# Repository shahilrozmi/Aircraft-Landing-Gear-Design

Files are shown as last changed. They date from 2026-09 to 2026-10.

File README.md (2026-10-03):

# Aircraft Landing Gear Design

Preliminary design and structural analysis of an **oleo-pneumatic main landing gear** for a generic 4–6 seat light aircraft. The project combines aircraft load-case definition, nonlinear landing-dynamics simulation, structural sizing, CAD/STEP geometry generation, and progressively refined FEA-oriented structural development using Python-based engineering tools.

## Project Overview

The design focuses on one single-wheel main landing gear leg for a generic low-wing tricycle aircraft.

### Baseline aircraft and landing-gear definition

- Aircraft mass: **1700 kg**
- Wheelbase: **2.35 m**
- Main-gear track: **3.20 m**
- Detailed main-gear wheel lateral offset: **120 mm**
- Static loaded tire radius: **175 mm**
- Physical oleo stroke: **230 mm**
- Static oleo sag: **50 mm**
- Structural ultimate factor: **1.5**

The project is developed progressively from aircraft-level loads and landing energy to component sizing, physical upper-attachment architecture, CAD geometry, FEA load-path validation, local mesh refinement, and geometry redesign.

## Engineering Workflow

### Phase 1 — Aircraft Loads and Landing Dynamics

The authoritative Phase 1 implementation is contained in:

- `phase1_loads/phase1_loads.py`
- `phase1_loads/phase1_dynamics.py`

The landing model uses a **2-DOF tire/oleo representation** with gas-spring and hydraulic-damping behavior.

Selected results:

| Quantity | Result |
|---|---:|
| Nominal peak oleo compression | **206.338 mm** |
| Nominal peak tire deflection | **44.961 mm** |
| Nominal peak ground reaction | **23.800 kN** |
| Nominal peak strut force | **23.038 kN** |
| Zero-lift demanded oleo stroke | **240.779 mm** |
| Zero-lift peak ground reaction | **28.284 kN** |
| Zero-lift peak strut force | **27.781 kN** |

`phase1_model_development/` preserves the development history and robustness studies. Those files are retained for traceability but are **not** the authoritative frozen Phase 1 model.

### Phase 2 — Structural Design and Oleo Architecture

Released preliminary oleo geometry includes:

- Outer barrel: **64 mm ID / 74 mm OD**
- Lower piston: **58 mm OD / 50 mm ID**
- Physical stroke: **230 mm**
- Equivalent orifice schedule: **10.301 → 9.742 mm**
- Fixed metering bore: **14 mm**

Phase 2 includes piston, barrel, bushing/gland, boss, axle, trunnion, brace, overlap/packaging, and traceability work. The repository retains the analytical scripts and associated CSV/TXT engineering records used to develop the architecture.

### Phase 2E3 — Upper Attachment, Physical Brace, and Horn/Clevis Development

The upper attachment evolved beyond the earlier B13C four-body baseline. The validated **B13F-3C** parent is now the retained source geometry for the later physical horn/clevis work.

Current B13F-3C parent highlights:

- 7075-T6 upper-head outer boss: **Ø106 mm × 78 mm**
- Continuous 300M shaft: **Ø38 mm × 175 mm**
- Head side passage: **Ø50 mm**
- Central passage: **Ø44 mm** over the retained center region
- Minimum shaft/head radial gap in the central relief: **3 mm**
- C63000 / AMS 4640 bronze bushings
- Separate 300M thrust collars
- **6 physical bodies** in the validated STEP parent
- Current-parent validation: **54 PASS / 0 FAIL**

The B14 work then physicalized the brace load path and added the source-connected horn/clevis geometry.

Selected B14 milestones:

- B14A source-connected combined brace reaction: **Mx = -16.856 kN·m**
- B14B preliminary physical-brace ultimate force: **67.424 kN**
- B14B-9 physical head/horn/clevis CAD: **62 PASS / 0 FAIL** geometry checks
- B14B-10 global physical-brace FEA load path: **closed** for global reaction/load-path validation and large-deflection sensitivity
- B14B-11: horn/head root transition and local-stress refinement

## Current Root-Transition / FEA Status

The current detailed work is the **B14B-11 root transition**.

### R6 development reference

A local R6 root-mesh sequence reached a design-stage result of **407.52 MPa** at 2.0 mm local sizing with stable global response. This was used as an intermediate reference while the radius trade continued.

### R8 local submodel

A later quadratic local-submodel study showed that the R8 peak was substantially more severe than the earlier coarse full-model screens suggested.

Retained R8 local result:

- 1.50 mm: **442.62 MPa**
- 1.00 mm: **697.48 MPa**
- 0.75 mm: **732.45 MPa**
- 1.00 → 0.75 mm peak change: **+5.014%**
- 0.75 mm fillet-average VM: **91.817 MPa**
- Maximum deformation: **0.73252 mm**

The 0.75 mm solution is treated as **near-converged / mesh-stabilized**, not as strictly mathematically converged. Under the generic project 7075 static screen, the **732.45 MPa** local peak is unacceptable and requires a geometry response.

### F2 reinforced-root redesign

The first B14B-11F redesign retained the basic root architecture but enlarged the section:

- **F2_BALANCED:** **95 × 115 mm** root section, **R12** blend
- Added mass versus the R8 head: approximately **0.615 kg**

A 1.0 mm local submodel gave:

- **24,801 nodes / 14,487 elements**
- Maximum deformation: **0.73252 mm**
- Fillet-average VM: **77.072 MPa** (**16.1% lower** than the retained R8 average)
- Fillet-scoped peak VM: **1995.7 MPa**

The extreme peak occurs at the termination of the new blend. Therefore **F2 is rejected as-is**, while the **95 × 115 mm reinforced-section concept is retained**.

## Current Next Step

**B14B-11F / F2B root redesign**:

- retain the **95 × 115 mm** reinforced root concept
- replace the abrupt constant-radius blend termination with a smoother/tangent transition
- rerun the **1.0 mm quadratic local screen**
- only refine to **0.75 mm** after the local peak becomes physically credible and the transition geometry is accepted
- update the full six-body parent only after the local redesign passes the screening gate

## Repository Structure

```text
Aircraft-Landing-Gear-Design/
├── README.md
├── CURRENT_STATE.md
├── UPLOAD_MANIFEST.md
├── FILE_INVENTORY.csv
├── requirements.txt
│
├── phase1_loads/
│   ├── phase1_loads.py
│   ├── phase1_dynamics.py
│   └── frozen CSV outputs
│
├── phase1_model_development/
│   ├── README.md
│   └── historical Phase 1 model revisions
│
└── phase2_structures/
    ├── preliminary component sizing / architecture
    ├── E2 release and traceability records
    ├── B13 / B13F upper-head and trunnion development
    ├── B14 physical-brace / horn-clevis development
    ├── B14B-10 FEA handoff and closeout records
    ├── B14B-11 radius trade / local-submodel / convergence work
    ├── B14B-11F redesign candidates
    └── current_design/
        └── retained B13-era interface sizing records
```

## Running the Python Analyses

Create a virtual environment and install the retained dependencies:

```bash
python -m venv .venv
```

Windows:

```bash
.venv\Scripts\activate
pip install -r requirements.txt
```

Principal Phase 1 analyses:

```bash
python phase1_loads/phase1_loads.py
python phase1_loads/phase1_dynamics.py
```

Phase 2 contains multiple design-stage scripts rather than one monolithic program. See `CURRENT_STATE.md` and `UPLOAD_MANIFEST.md` for the current analysis chain and authoritative revisions.

## Remaining Work

Major later-stage items include:

- F2B root-transition redesign and local FEA screen
- final horn/head root geometry selection and full-parent confirmation solve
- local stress convergence of the accepted geometry
- production fit and running-clearance definition
- lubrication, wear, and fretting assessment
- fatigue and fracture analysis
- final shaft-retention hardware
- detailed tolerances and surface finishes
- corrosion protection
- complete airframe attachment definition
- certification / regulatory load mapping
- finalized landing-gear assembly and detailed component geometry in CATIA V5
- optional retraction-mechanism development

## Project Notes

`CURRENT_STATE.md` is the recommended starting point for the latest engineering status.

`UPLOAD_MANIFEST.md` identifies the retained/current analysis chain and explains the curation rules used for GitHub.

This repository represents an **educational preliminary engineering design project**, not a certified aircraft component design.

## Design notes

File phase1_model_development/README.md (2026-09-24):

# Phase 1 Model Development Archive

These scripts are retained as **historical engineering evidence**, not as the current source of truth.

For current/frozen Phase 1 results, use:

- `../phase1_loads/phase1_loads.py`
- `../phase1_loads/phase1_dynamics.py`
- `../phase1_loads/phase1_load_envelope.csv`
- `../phase1_loads/phase1_dynamic_robustness.csv`

The archived scripts all execute successfully in the current audit environment, but they represent the model-development chain that led to the frozen consolidated model.

## What each archived script shows

- `landing_dynamic_v1.py` — V0.3 predecessor: 1-DOF energy-equivalent oleo model, hand-analysis targets, gas sizing, and smooth hydraulic metering. Useful for showing how the 205 mm target stroke and 10.301 -> 9.742 mm metering schedule were established. Superseded by the 2-DOF model for final landing loads.
- `landing_dynamic_v04_2dof.py` — V0.4 2-DOF sprung/unsprung tire-oleo model. Reproduces the accepted nominal result (206.338 mm stroke, 23.800 kN ground reaction, 23.038 kN strut force), extension-stop release, energy balance, and 20/30/40 kg unsprung-mass sensitivity.
- `landing_dynamic_v05_robustness.py` — V0.5 robustness study. Contains the unsprung-mass, sink-speed, **tire-stiffness**, and retained-lift sweeps plus selected combined robustness corners. The tire-stiffness sweep and combined corner studies are useful development evidence and are not all duplicated in the consolidated `phase1_dynamics.py`.
- `landing_dynamic_v05b_virtual_stroke.py` — V0.5b zero-lift virtual-stroke diagnostic. Reproduces the accepted 3.048 m/s zero-lift demand (240.779 mm stroke, 28.284 kN ground reaction, 27.781 kN strut force) and also evaluates the 1.10 Vd zero-lift case (248.258 mm demanded stroke).

## Interpretation rule

If an archived development result differs in framing or screening status from the frozen Phase 1 sources, the files in `phase1_loads/` govern. Do not use this archive to retune the frozen model unless the project is deliberately reopened.

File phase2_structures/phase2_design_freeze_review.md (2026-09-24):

# Landing_Gear_Design_Project — Phase 2 Preliminary Design Baseline V1

**Review outcome:** PRELIMINARY BASELINE READY — OPEN DETAIL/PACKAGING ITEMS REMAIN

This report is generated from the Phase 1 / Phase 2 CSV calculation chain. Calculated stresses, reactions, and margins are not transcribed from chat.

## Status summary

| Status | Count |
|---|---:|
| FROZEN | 11 |
| LOCK_PRELIMINARY | 22 |
| KEEP_PARAMETRIC | 8 |
| DEFER_DETAIL_FEA | 2 |

## Baseline

| Subsystem | Parameter | Value | Unit | Status | Source |
|---|---|---:|---|---|---|
| Project / frozen input | Aircraft mass | 1700.0 | kg | FROZEN | Phase 0 / Phase 1 / Phase 2B |
| Project / frozen input | Screening weight used in Phase 1 | 16.68 | kN | FROZEN | Phase 0 / Phase 1 / Phase 2B |
| Project / frozen input | Wheelbase | 2.35 | m | FROZEN | Phase 0 / Phase 1 / Phase 2B |
| Project / frozen input | Main-gear track | 3.2 | m | FROZEN | Phase 0 / Phase 1 / Phase 2B |
| Project / frozen input | Wheel/strut lateral offset e | 120.0 | mm | FROZEN | Phase 0 / Phase 1 / Phase 2B |
| Project / frozen input | Static loaded tire radius | 175.0 | mm | FROZEN | Phase 0 / Phase 1 / Phase 2B |
| Project / frozen input | Physical oleo stroke | 230.0 | mm | FROZEN | Phase 0 / Phase 1 / Phase 2B |
| Project / frozen input | Static oleo sag | 50.0 | mm | FROZEN | Phase 0 / Phase 1 / Phase 2B |
| Project / frozen input | Full-extension U-to-A length | 525.0 | mm | FROZEN | Phase 0 / Phase 1 / Phase 2B |
| Project / frozen input | Static U-to-A length | 475.0 | mm | FROZEN | Phase 0 / Phase 1 / Phase 2B |
| Project / frozen input | Ultimate factor | 1.5 | - | FROZEN | Phase 0 / Phase 1 / Phase 2B |
| Lower piston | Structural OD | 58.0 | mm | LOCK_PRELIMINARY | phase2_piston_sizing.csv |
| Lower piston | Wall thickness | 4.0 | mm | LOCK_PRELIMINARY | phase2_piston_sizing.csv |
| Outer barrel | Bore / ID | 64.0 | mm | LOCK_PRELIMINARY | phase2_barrel_sizing.csv |
| Outer barrel | Smooth wall thickness | 5.0 | mm | LOCK_PRELIMINARY | phase2_barrel_sizing.csv |
| Outer barrel | Smooth OD | 74.0 | mm | LOCK_PRELIMINARY | phase2_barrel_sizing.csv |
| Guide system | Lower bushing static station h_L | 250.0 | mm above axle | LOCK_PRELIMINARY | phase2_packaging_overlap.csv |
| Guide system | Bushing spacing | 150.0 | mm | LOCK_PRELIMINARY | phase2_packaging_overlap.csv |
| Guide system | Upper bushing static station h_U | 400.0 | mm above axle | LOCK_PRELIMINARY | phase2_packaging_overlap.csv |
| Guide system | Bushing axial length | 30.0 | mm | LOCK_PRELIMINARY | phase2_bushing_material_gland_requirements.csv |
| Guide system | Bushing material | C63000 / AMS 4640 Ni-Al bronze |  | LOCK_PRELIMINARY | phase2_bushing_material_gland_requirements.csv |
| Guide system | Bushing radial wall | 3.0 | mm | LOCK_PRELIMINARY | phase2_bushing_material_gland_requirements.csv |
| Guide / packaging | Top guide-surface overrun | 20.0 | mm | KEEP_PARAMETRIC | phase2_packaging_overlap.csv |
| Guide / packaging | Required piston guide-surface length | 485.0 | mm | KEEP_PARAMETRIC | phase2_packaging_overlap.csv |
| Gland | Architecture | Integral shoulder + bronze guide/seal carrier + threaded gland nut |  | LOCK_PRELIMINARY | phase2_gland_retainer_sizing.csv |
| Gland | Thread envelope | M70 x 2 equivalent 60-deg envelope |  | KEEP_PARAMETRIC | phase2_gland_retainer_sizing.csv |
| Gland | Thread engagement | 12.0 | mm | KEEP_PARAMETRIC | phase2_gland_retainer_sizing.csv |
| Lower barrel boss | Local boss OD | 84.0 | mm | LOCK_PRELIMINARY | phase2_gland_retainer_sizing.csv |
| Lower barrel boss | Boss-to-smooth-barrel transition land | 15.0 | mm | KEEP_PARAMETRIC | phase2_lower_barrel_boss_sizing.csv |
| Lower barrel boss | Actual fillet radius / local Kt | OPEN |  | DEFER_DETAIL_FEA | phase2_lower_barrel_boss_sizing.csv |
| Axle / spindle | Smooth root OD | 50.0 | mm | LOCK_PRELIMINARY | phase2_axle_sizing.csv |
| Axle / spindle | Smooth root wall | 8.0 | mm | LOCK_PRELIMINARY | phase2_axle_sizing.csv |
| Axle / spindle | Axle-to-piston local transition | OPEN |  | DEFER_DETAIL_FEA | phase2_axle_sizing.csv |
| Upper attachment | Trunnion architecture | Two bearings on +x axis + independent Mx brace path |  | LOCK_PRELIMINARY | phase2_upper_trunnion_sizing.csv |
| Upper attachment | Trunnion journal diameter | 32.0 | mm | LOCK_PRELIMINARY | phase2_upper_trunnion_sizing.csv |
| Upper attachment | Trunnion bearing width | 25.0 | mm | LOCK_PRELIMINARY | phase2_upper_trunnion_sizing.csv |
| Upper attachment | Trunnion support span | 120.0 | mm | KEEP_PARAMETRIC | phase2_upper_trunnion_sizing.csv |
| Upper brace | Tube OD | 25.0 | mm | LOCK_PRELIMINARY | phase2_upper_brace_sizing.csv |
| Upper brace | Tube wall | 3.0 | mm | LOCK_PRELIMINARY | phase2_upper_brace_sizing.csv |
| Upper brace | Pin diameter | 18.0 | mm | LOCK_PRELIMINARY | phase2_upper_brace_sizing.csv |
| Upper brace | Pin-bushing projected width | 20.0 | mm | LOCK_PRELIMINARY | phase2_upper_brace_sizing.csv |
| Upper brace | Effective perpendicular moment arm | 250.0 | mm | KEEP_PARAMETRIC | phase2_upper_brace_sizing.csv |
| Upper brace | Pin-to-pin free length | 350.0 | mm | KEEP_PARAMETRIC | phase2_upper_brace_sizing.csv |

## Compatibility / structural review

| Check | Result | Detail | Severity |
|---|---|---|---|
| Piston OD matches D5 bearing interface | PASS | piston OD = 58.0 mm | REQUIRED |
| Bushing OD matches barrel bore | PASS | bushing OD = 64.0 mm, barrel ID = 64.0 mm | REQUIRED |
| Bushing radial stack is self-consistent | PASS | (barrel ID - piston OD)/2 = 3.0 mm, D5 bushing wall = 3.0 mm | REQUIRED |
| Full lower-bushing engagement at physical stroke | PASS | reserve = +55.0 mm | REQUIRED |
| Full lower-bushing engagement in V0.5b diagnostic | PASS | reserve = +44.2 mm | DIAGNOSTIC |
| Local gland boss is thicker than smooth barrel | PASS | boss OD = 84.0 mm, smooth barrel OD = 74.0 mm | REQUIRED |
| Gland boss retains positive thread-root wall | PASS | boss root wall = 7.00 mm | REQUIRED |
| Gland nut retains positive root wall over through-bore | PASS | gland root wall = 4.27 mm | REQUIRED |
| Piston preliminary structural screen | PASS | ultimate VM = 1023.2 MPa, MS = +0.820 | REQUIRED |
| Barrel preliminary structural/pressure screen | PASS | ultimate VM = 595.2 MPa, MS = +2.128 | REQUIRED |
| Lower boss transition at review Kt | PASS | Kt = 2.0, ultimate VM = 230.1 MPa, MS = +7.091 | REQUIRED |
| Axle root preliminary screen | PASS | ultimate VM = 481.2 MPa, MS = +2.870 | REQUIRED |
| Upper trunnion preliminary screen | PASS | ultimate VM = 460.0 MPa, bearing p = 101.9 MPa | REQUIRED |
| Upper brace tube preliminary screen | PASS | MS ultimate = +8.530, MS buckling = +3.871 | REQUIRED |
| Upper brace pin/bushing preliminary screen | PASS | pin shear MS = +12.505, bearing MS = +2.676 | REQUIRED |
| Upper Mx load path exists | PASS | brace effective arm = 250 mm; calculated ultimate brace force = 40.51 kN | REQUIRED |
| Axle-to-piston local root geometry resolved | OPEN | smooth piston ID = 50.0 mm and axle OD = 50.0 mm; this is not a through-fit requirement, but the forged/welded/local axle-to-piston transition has not yet been defined | OPEN_DETAIL |
| Physical upper-barrel/cavity package above U resolved | OPEN | current packaging model requires 190.0 mm piston-top intrusion above equivalent datum U at physical stroke | OPEN_PACKAGING |
| Actual trunnion/brace airframe fitting geometry resolved | OPEN | journal spacing and brace arm/free length remain preliminary until airframe fitting CAD is established | OPEN_PACKAGING |

## Open items

| Priority | Item | Resolution gate |
|---|---|---|
| HIGH | Axle-to-piston lower-end architecture | Detailed lower-strut CAD + local stress/FEA |
| HIGH | Upper barrel / piston cavity above equivalent datum U | Full strut packaging CAD |
| HIGH | Physical trunnion / brace airframe fitting coordinates | Airframe-interface CAD / structural arrangement |
| MEDIUM | Gland production thread / lock / seal definition | Detailed gland design |
| MEDIUM | Actual fillet radii and stress concentrations | Detailed CAD + FEA/fatigue |
| MEDIUM | Wheel bearing seats / brake flange / wheel-retention spindle detail | Wheel/brake interface design |
| MEDIUM | Brace clevis/lug/pin bending details | Detailed upper-joint design |
| LATER | Fatigue / fracture / fretting / corrosion / surface treatment | Later structural substantiation phase |
| LATER | Retraction mechanism | Optional later extension |

## Baseline rule

Items marked **LOCK_PRELIMINARY** are now the Phase 2 baseline and should be used by downstream analyses unless a deliberate design-change decision reopens them. **KEEP_PARAMETRIC** items remain active packaging variables. **DEFER_DETAIL_FEA** items are intentionally unresolved until the appropriate detailed-design stage.

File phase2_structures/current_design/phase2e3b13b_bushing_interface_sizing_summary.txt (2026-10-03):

======================================================================================================================
 DOCUMENTATION BACKFILL — current_design\phase2e3b13b_bushing_interface_sizing.py
======================================================================================================================

Python executable: C:\Users\Shahi\AppData\Local\Python\pythoncore-3.14-64\python.exe
Working directory: C:\Users\Shahi\OneDrive\Documents\Python\Landing_Gear_Project_UPLOAD_v2\phase2_structures\current_design
Return code: 0

STDOUT
----------------------------------------------------------------------------------------------------------------------
============================================================================================================
 PHASE 2E3-B13B — SHAFT / HEAD BUSHING INTERFACE PRELIMINARY SIZING V0.1
============================================================================================================

--- INPUT / ARCHITECTURE BASIS ---
300M shaft nominal diameter:                38.000 mm
7075 head OD, working CAD input:           106.000 mm
AMS 4640 static bearing screen:            413.685 MPa
B2 recovered reference reaction:           112.640 kN
B12 conservative per-bushing envelope:     166.160 kN
Load note: B12 reaction is intentionally used as a conservative per-bushing screen;
           B13C contact FEA will resolve the actual bushing load distribution.

--- STATIC-BEARING MINIMUM LENGTHS ---
Length required at B2 reference reaction:    7.165 mm
Length required at B12 envelope:            10.570 mm
Interpretation: static projected bearing capacity alone does NOT control a 25–30 mm bushing length.

--- PRACTICAL SHORTLIST FILTERS (NON-CERTIFICATION / PACKAGING ONLY) ---
Minimum candidate length retained:          25.000 mm
Minimum bronze radial wall retained:         5.000 mm
Minimum head radial ligament retained:      25.000 mm

--- PRACTICAL SHORTLIST ---
    L    OD    wall  head lig      gap      p_ID    MS_brg      p_OD
----------------------------------------------------------------------------
   25    48    5.00     29.00    56.00     174.9     1.365     138.5
   25    50    6.00     28.00    56.00     174.9     1.365     132.9
   25    52    7.00     27.00    56.00     174.9     1.365     127.8
   25    54    8.00     26.00    56.00     174.9     1.365     123.1
   25    56    9.00     25.00    56.00     174.9     1.365     118.7
   30    48    5.00     29.00    46.00     145.8     1.838     115.4
   30    50    6.00     28.00    46.00     145.8     1.838     110.8
   30    52    7.00     27.00    46.00     145.8     1.838     106.5
   30    54    8.00     26.00    46.00     145.8     1.838     102.6
   30    56    9.00     25.00    46.00     145.8     1.838      98.9
   35    48    5.00     29.00    36.00     124.9     2.311      98.9
   35    50    6.00     28.00    36.00     124.9     2.311      94.9
   35    52    7.00     27.00    36.00     124.9     2.311      91.3
   35    54    8.00     26.00    36.00     124.9     2.311      87.9
   35    56    9.00     25.00    36.00     124.9     2.311      84.8

--- WORKING CANDIDATE FOR B13B/B13C DEVELOPMENT ---
Nominal shaft / bushing ID:                 38.000 mm
Bushing OD:                                 50.000 mm
Bushing length, each side:                  30.000 mm
Bronze radial wall:                          6.000 mm
Remaining head radial ligament:             28.000 mm
Central unbushed gap:                       46.000 mm
Shaft-side projected p @ B12 envelope:     145.754 MPa
AMS 4640 static bearing MS:                 +1.838
Housing-side projected p, descriptive:     110.773 MPa

SELECTION REASON
- Ø50 x 30 mm gives a 6 mm bronze wall and 28 mm current-CAD head radial ligament.
- Its 30 mm length is far above the static-capacity mathematical minimum.
- It preserves a practical, round geometry for the next interference-fit/contact study.
- This is a WORKING candidate, not a final certified bushing dimension.

--- OPEN ITEMS BEFORE GEOMETRY FREEZE ---
1. Bronze-to-7075 interference/retention fit: DEFERRED to B13B V0.2.
2. Shaft-to-bushing running clearance:       TBD from fit/lubrication/wear basis.
3. 7075 bearing/net-section/shear-out:        requires local head mechanics / FEA.
4. Fretting, wear, lubrication, fatigue:      OPEN.
5. Actual bushing reaction split:             resolve in B13C nonlinear contact FEA.

OUTPUT FILES
Full candidate sweep: C:\Users\Shahi\OneDrive\Documents\Python\Landing_Gear_Project_UPLOAD_v2\phase2_structures\current_design\phase2e3b13b_bushing_trade.csv
Summary:              C:\Users\Shahi\OneDrive\Documents\Python\Landing_Gear_Project_UPLOAD_v2\phase2_structures\current_design\phase2e3b13b_summary.txt
============================================================================================================

STDERR
----------------------------------------------------------------------------------------------------------------------

======================================================================================================================

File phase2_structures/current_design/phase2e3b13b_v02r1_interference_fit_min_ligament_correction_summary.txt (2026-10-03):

======================================================================================================================
 DOCUMENTATION BACKFILL — current_design\phase2e3b13b_v02r1_interference_fit_min_ligament_correction.py
======================================================================================================================

Python executable: C:\Users\Shahi\AppData\Local\Python\pythoncore-3.14-64\python.exe
Working directory: C:\Users\Shahi\OneDrive\Documents\Python\Landing_Gear_Project_UPLOAD_v2\phase2_structures\current_design
Return code: 0

STDOUT
----------------------------------------------------------------------------------------------------------------------
==========================================================================================================
 PHASE 2E3-B13B V0.2R1 — INTERFERENCE-FIT MINIMUM-LIGAMENT CORRECTION
==========================================================================================================

--- CORRECTED GEOMETRY INTERPRETATION ---
Head lateral width:                     106.000 mm
Head minimum vertical height:            78.000 mm
Bushing seat diameter:                   50.000 mm
Minimum vertical ligament:               14.000 mm
Side ligament:                           28.000 mm
V0.2's 28 mm value was the SIDE ligament, not the minimum ligament.

--- CORRECTED FIT SENSITIVITY ---
  delta_d     p_fit     VM7075     MS7075    VMbronze    MSbronze
----------------------------------------------------------------------
    0.005      1.53       4.63    107.738        7.25      56.119
    0.010      3.06       9.25     53.369       14.50      27.559
    0.015      4.59      13.88     35.246       21.74      18.040
    0.020      6.12      18.50     26.184       28.99      13.280
    0.025      7.65      23.13     20.748       36.24      10.424
    0.030      9.18      27.75     17.123       43.49       8.520
    0.040     12.25      37.01     12.592       57.98       6.140
    0.050     15.31      46.26      9.874       72.48       4.712
    0.060     18.37      55.51      8.061       86.98       3.760
    0.080     24.49      74.01      5.796      115.97       2.570
    0.100     30.62      92.52      4.437      144.96       1.856
    0.150     45.92     138.77      2.625      217.44       0.904
    0.200     61.23     185.03      1.718      289.92       0.428

--- LINEAR ELASTIC FIRST SCREEN ---
7075 yield surrogate:                     0.544 mm diametral interference
Bronze proof surrogate:                   0.286 mm diametral interference
First material screen:                    0.286 mm
Interpretation: the corrected minimum-ligament surrogate still leaves tens-of-micrometre
fit sensitivities comfortably elastic. This does NOT define the production fit.

OUTPUT FILES
CSV:     C:\Users\Shahi\OneDrive\Documents\Python\Landing_Gear_Project_UPLOAD_v2\phase2_structures\current_design\phase2e3b13b_v02r1_interference_sweep.csv
Summary: C:\Users\Shahi\OneDrive\Documents\Python\Landing_Gear_Project_UPLOAD_v2\phase2_structures\current_design\phase2e3b13b_v02r1_summary.txt
==========================================================================================================

STDERR
----------------------------------------------------------------------------------------------------------------------

======================================================================================================================

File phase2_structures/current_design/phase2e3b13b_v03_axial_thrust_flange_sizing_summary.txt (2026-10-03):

======================================================================================================================
 DOCUMENTATION BACKFILL — current_design\phase2e3b13b_v03_axial_thrust_flange_sizing.py
======================================================================================================================

Python executable: C:\Users\Shahi\AppData\Local\Python\pythoncore-3.14-64\python.exe
Working directory: C:\Users\Shahi\OneDrive\Documents\Python\Landing_Gear_Project_UPLOAD_v2\phase2_structures\current_design
Return code: 0

STDOUT
----------------------------------------------------------------------------------------------------------------------
================================================================================================================
 PHASE 2E3-B13B V0.3 — FLANGED-BUSHING AXIAL THRUST-PATH PRELIMINARY SIZING
================================================================================================================

--- FROZEN / WORKING INPUTS ---
LC5 limit |Fx|:                           8.87376 kN
LC5 ultimate |Fx|:                       13.31064 kN
Shaft / bushing nominal ID:                38.000 mm
Sleeve OD:                                 50.000 mm
Sleeve length each side:                   30.000 mm
Head face -> bearing inner edge gap:        9.500 mm
AMS 4640 preliminary static screen:       413.685 MPa

--- ARCHITECTURE RULE ---
One flanged bushing may conservatively carry the full axial |Fx| in either direction.
Mx remains on the independent brace path; flange/shaft retention is NOT credited for Mx.

--- CANDIDATE TRADE ---
   Df    tf   seat_w    pBr_ult     MS_Br    pAl_ult   gap_rem    pkg
----------------------------------------------------------------------------------
   52   2.0     1.00      13.45    29.756      83.08      7.50   OPEN
   52   3.0     1.00      13.45    29.756      83.08      6.50   OPEN
   52   4.0     1.00      13.45    29.756      83.08      5.50   OPEN
   52   5.0     1.00      13.45    29.756      83.08      4.50   OPEN
   54   2.0     2.00      11.51    34.931      40.74      7.50   OPEN
   54   3.0     2.00      11.51    34.931      40.74      6.50   OPEN
   54   4.0     2.00      11.51    34.931      40.74      5.50   OPEN
   54   5.0     2.00      11.51    34.931      40.74      4.50   OPEN
   56   2.0     3.00      10.02    40.301      26.65      7.50   OPEN
   56   3.0     3.00      10.02    40.301      26.65      6.50   OPEN
   56   4.0     3.00      10.02    40.301      26.65      5.50   OPEN
   56   5.0     3.00      10.02    40.301      26.65      4.50   OPEN
   58   2.0     4.00       8.83    45.866      19.62      7.50   PASS
   58   3.0     4.00       8.83    45.866      19.62      6.50   PASS
   58   4.0     4.00       8.83    45.866      19.62      5.50   PASS
   58   5.0     4.00       8.83    45.866      19.62      4.50   PASS
   60   2.0     5.00       7.86    51.627      15.41      7.50   PASS
   60   3.0     5.00       7.86    51.627      15.41      6.50   PASS
   60   4.0     5.00       7.86    51.627      15.41      5.50   PASS
   60   5.0     5.00       7.86    51.627      15.41      4.50   PASS
   62   2.0     6.00       7.06    57.583      12.61      7.50   PASS
   62   3.0     6.00       7.06    57.583      12.61      6.50   PASS
   62   4.0     6.00       7.06    57.583      12.61      5.50   PASS
   62   5.0     6.00       7.06    57.583      12.61      4.50   PASS
   64   2.0     7.00       6.39    63.734      10.62      7.50   PASS
   64   3.0     7.00       6.39    63.734      10.62      6.50   PASS
   64   4.0     7.00       6.39    63.734      10.62      5.50   PASS
   64   5.0     7.00       6.39    63.734      10.62      4.50   PASS

--- WORKING FLANGE FOR B13C CAD/FEA ---
Flange OD:                                 60.000 mm
Flange thickness:                           3.000 mm
Positive radial seat on 7075 face:          5.000 mm
Bronze thrust pressure, ultimate:           7.861 MPa
Bronze static-screen margin:              +51.627
7075 head-face avg pressure, ultimate:     15.407 MPa
Gap remaining before bearing inner edge:    6.500 mm

SELECTION REASON
- Static axial thrust pressure is extremely low relative to the preliminary bronze screen.
- Ø60 gives a 5 mm radial positive seat outside the Ø50 sleeve bore.
- 3 mm flange thickness leaves 6.5 mm of the current 9.5 mm external gap.
- Thickness is a PROVISIONAL packaging/FEA starting value; static face pressure does not size it.
- Flange-root bending, local 7075 face stress, washer detail, wear and fatigue remain for FEA/detail design.

--- RESULTING B13C GEOMETRY INTENT ---
Per side bronze bushing: sleeve Ø50 OD x Ø38 nominal ID x 30 mm long
                         integral flange Ø60 OD x 3 mm thick
Two bushings are inserted from opposite sides of the head.
The flange is the positive axial seat; the shaft shoulder/thrust washer acts on the bronze flange.
The center of the head must NOT retain an exposed Ø38 aluminum land that can touch the shaft.

--- IMPORTANT OPEN ITEM FOR CAD ---
Central shaft clearance/relief diameter is NOT frozen in V0.3.
For B13C geometry, either keep the full head passage relieved to the Ø50 bushing OD,
or deliberately size a smaller central relief bore > Ø38 after a clearance/tolerance study.
Do NOT leave the old Ø38 7075 bore exposed between the two bushings.

OUTPUT FILES
Trade CSV: C:\Users\Shahi\OneDrive\Documents\Python\Landing_Gear_Project_UPLOAD_v2\phase2_structures\current_design\phase2e3b13b_v03_thrust_flange_trade.csv
Summary:   C:\Users\Shahi\OneDrive\Documents\Python\Landing_Gear_Project_UPLOAD_v2\phase2_structures\current_design\phase2e3b13b_v03_summary.txt
================================================================================================================

STDERR
----------------------------------------------------------------------------------------------------------------------

======================================================================================================================

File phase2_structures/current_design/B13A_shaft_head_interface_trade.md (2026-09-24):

# Phase 2E3-B13A — Shaft / Head Interface Architecture Trade

## Working architecture

**Selected working concept:** removable Ø38 mm 300M cross-pin running in two replaceable
C63000 / AMS 4640 nickel-aluminum-bronze head bushings.

Load path:

`7075-T6 head -> bronze bushings -> 300M shaft -> external airframe bearings`

The independent brace / lock-link remains the reaction path for `Mx`.

## Why B13 exists

B12/B12C showed that the extreme local head stress was controlled by the termination of the
idealized bonded shaft/head interface. A head-only path offset approximately 0.5 mm from that
termination dropped to roughly 191–238 MPa, while the exact interface edge remained far higher.
The bonded model is therefore retained only as historical sensitivity evidence, not as the final
physical interface.

## Concept trade

| Concept | Benefit | Main drawback | B13 disposition |
|---|---|---|---|
| Direct 300M-to-7075 interference fit | simple, rigid | adds fit stress directly to 7075; poorer serviceability | not preferred |
| Replaceable bronze bushings + removable pin | replaceable wear surface; realistic pin joint | needs fit/contact analysis | **working selection** |
| Split/clamped boss | removable and rigidizable | more parts, preload and package complexity | reserve option |

## Freeze boundary

B13A freezes the *architecture*, not final dimensions.

Working starting dimensions for B13B:
- shaft nominal diameter: 38 mm
- current CAD head OD input: 106 mm
- bushing material: C63000 / AMS 4640 nickel-aluminum bronze
- initial practical candidate explored: 50 mm OD × 30 mm length per side

Still open:
- bronze-to-7075 interference/retention fit
- shaft running clearance
- lubrication/wear/fretting
- final bushing OD and length
- 7075 local bearing/net-section/shear-out
- nonlinear contact FEA

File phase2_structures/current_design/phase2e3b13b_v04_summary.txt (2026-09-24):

================================================================================================================
 PHASE 2E3-B13B V0.4 — CENTRAL SHAFT RELIEF / HEAD-SECTION TRADE
================================================================================================================

--- BASELINE ---
Head cross-section:                    106.0 x 78.0 mm
Original bore:                         Ø38.0 mm
Original upper/lower ligament:         20.0 mm
Original side ligament:                34.0 mm

--- RELIEF TRADE ---
  Drel   clr_r   v_lig   s_lig      dA%     dIy%     dIz%   sig_sens    MSsens
--------------------------------------------------------------------------------------
    40    1.00   19.00   33.00    -1.72    -0.57    -0.31      56.46     7.908
    42    2.00   18.00   32.00    -3.52    -1.23    -0.66      59.60     7.439
    44    3.00   17.00   31.00    -5.42    -2.00    -1.07      63.11     6.971
    46    4.00   16.00   30.00    -7.40    -2.87    -1.54      67.05     6.502
    48    5.00   15.00   29.00    -9.47    -3.87    -2.07      71.52     6.033
    50    6.00   14.00   28.00   -11.63    -5.00    -2.68      76.63     5.564

--- WORKING B13C CENTRAL RELIEF ---
Selected working relief:              Ø50.0 mm THROUGH
Shaft-to-aluminum radial clearance:    6.00 mm
Minimum vertical ligament:             14.00 mm
Side ligament:                         28.00 mm
Net-area change vs Ø38 bore:           -11.63 %
Iy change vs Ø38 bore:                 -5.00 %
Iz change vs Ø38 bore:                 -2.68 %
B11 scaled nominal stress sensitivity: 76.63 MPa
Yield margin on that sensitivity only: +5.564

SELECTION REASON
- Ø50 through-bore matches the bronze sleeve OD and eliminates exposed Ø38 aluminum.
- It avoids an internal bore shoulder at the bushing ends.
- It gives 6 mm radial clearance between the Ø38 shaft and 7075 center passage.
- Relative to the old Ø38 bore, the centered-section area falls about 11.6%,
  Iy about 5.0%, and Iz about 2.7%; these are acceptable to TAKE TO FEA, not final approval.
- The minimum vertical ligament becomes 14 mm, so B13C local head/contact FEA is mandatory.

B13C CAD INTENT
- Machine/model one Ø50 passage through the head.
- Install one 30 mm-long flanged bronze bushing from each side.
- Leave the center 46 mm of the Ø50 passage unoccupied.
- Shaft is Ø38 nominal; it contacts bronze ID surfaces only, never 7075.
- Keep the Ø60 x 3 mm flange working geometry from B13B V0.3.
- Do not add a central keeper hole/keyway through the Ø38 shaft.
- Mx remains on the independent brace path.

OUTPUT FILES
Trade CSV: C:\Users\Shahi\OneDrive\Documents\Python\Landing_Gear_Project\phase2_structures\current_design\phase2e3b13b_v04_central_relief_trade.csv
Summary:   C:\Users\Shahi\OneDrive\Documents\Python\Landing_Gear_Project\phase2_structures\current_design\phase2e3b13b_v04_summary.txt
================================================================================================================

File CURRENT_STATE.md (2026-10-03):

# Landing Gear Design Project — Current Repository State

This repository is a curated engineering snapshot for continued development, reproducibility, and traceability. Large machine-specific Python environments, caches, and superseded artifacts are intentionally excluded.

## Authoritative project state

### Phase 1 — frozen loads and landing dynamics

Use `phase1_loads/phase1_loads.py` and `phase1_loads/phase1_dynamics.py` as the authoritative Phase 1 sources.

Frozen load-envelope highlights:

- LC1 / LC2 / LC3 vertical limit per detailed main: **25.02 kN**; ultimate **37.53 kN**
- LC4 vertical limit per main: **11.0922 kN** with lateral **±8.34 kN**
- LC5 limit: **Fx = -8.87376 kN**, **Fz = 11.0922 kN**
- LC5 ultimate: **Fx = -13.31064 kN**, **Fz = 16.6383 kN**

Landing-dynamics highlights:

- Nominal peak oleo stroke: **206.338 mm**
- Nominal peak tire deflection: **44.961 mm**
- Nominal peak ground reaction: **23.800 kN**
- Nominal peak strut force: **23.038 kN**
- Zero-lift virtual-stroke demand: **240.779 mm**
- Zero-lift peak ground reaction: **28.284 kN**
- Zero-lift peak strut force: **27.781 kN**

`phase1_model_development/` remains a non-authoritative development-history archive.

### Phase 2E2 — released preliminary oleo architecture

`phase2_structures/phase2e2_v1_release_report.txt` remains the authoritative E2 release record.

Release status: **PASS (22/22 checks)** at preliminary architecture / structural-screen level.

Released working geometry / hydraulic architecture:

- barrel: **64 mm ID / 74 mm OD**
- piston: **58 mm OD / 50 mm ID**
- physical stroke: **230 mm**
- smooth clamped-linear equivalent orifice: **10.301 → 9.742 mm over 205 mm**
- fixed metering bore: **14 mm**
- preliminary E3 interface: **498.780 mm above U**

### Phase 2E3 — upper-head / trunnion evolution

B1–B12 remain the retained design history leading to the B13 family.

The previous GitHub snapshot stopped at the **B13C** four-body geometry. That geometry is now historical rather than the active CAD parent.

#### Current retained parent — B13F-3C

The validated parent for the later B14 horn/clevis work is:

`phase2_structures/phase2e3_b13f_3c_d44_r1p5_t3p5_left_collar_partial_relief.step`

Key geometry:

- 7075-T6 upper-head boss: **Ø106 × 78 mm**
- continuous 300M shaft: **Ø38 × 175 mm**
- head side passage: **Ø50 mm**
- central passage: **Ø44 mm** over the retained center region
- minimum shaft/head radial gap: **3 mm**
- right bronze sleeve: **Ø50/Ø38 × 30 mm**
- left bronze flange: **Ø60/Ø38 × 3.5 mm**
- separate left/right 300M thrust collars
- physical bodies: **6**
- validation: **54 PASS / 0 FAIL**

The validation record explicitly supersedes the old B13C model as the current parent for B14B-9.

## B14 physical-brace / horn-clevis development

### B14A — source-connected ANSYS reaction record

`phase2e3b14a_freeze_record.csv` is the load-source handoff for later B14B work.

Combined brace reaction:

- **Mx = -16.856 kN·m**
- force + moment + pressure superposition residual: **0.001260%**

### B14B — physical brace

The physical brace architecture converts the frozen B14A moment reaction into an axial two-force member.

Working values:

- effective Mx arm: **250 mm**
- pin-to-pin length: **350 mm**
- ultimate brace force: **67.424 kN**
- tube working section: **25 mm OD × 3 mm wall**

### B14B-9 — physical horn / clevis CAD

`phase2e3b14b9_head_horn_clevis_v01.step` adds the source-connected horn/clevis to the validated B13F-3C parent.

- equivalent root section entering the horn: **85 × 95 mm**
- pin bore: **Ø18 mm**
- geometry validation: **62 PASS / 0 FAIL**
- gate: `PASS_B14B9_GEOMETRY_FOR_LOCAL_FEA`

### B14B-10 — physical-brace FEA closeout

B14B-10 is **closed for global physical-brace load-path validation and large-deflection sensitivity**.

The large-deflection sensitivity showed only small changes in global response, including approximately:

- brace-force magnitude: **-0.0283%**
- maximum deformation: **+0.1484%**
- maximum von Mises stress: **+0.0144%**

The sharp horn/head root remained the governing local hotspot, so the next work moved to local transition refinement rather than treating the B14B-10 local maximum as final.

## B14B-11 — horn/head root transition refinement

### R6 development reference

The R6 local root-mesh sequence reached:

- 3.0 mm: **411.23 MPa**
- 2.5 mm: **408.46 MPa**
- 2.0 mm: **407.52 MPa**

The 2.5 → 2.0 mm change was **0.230%**, so R6 was considered converged enough for that design stage.

### R8 local submodel

Later targeted refinement showed that the raw full-model root maximum was not a reliable converged local stress. A quadratic local-submodel workflow was therefore created.

Retained R8 convergence sequence:

- 1.50 mm: **442.62 MPa**
- 1.00 mm: **697.48 MPa**
- 0.75 mm: **732.45 MPa**

At 0.75 mm:

- nodes/elements: **19,081 / 11,045**
- fillet-average VM: **91.817 MPa**
- maximum total deformation: **0.73252 mm**
- 1.00 → 0.75 mm peak change: **+5.014%**

Disposition:

- treat **732.45 MPa** as the current conservative R8 local design-screen peak
- describe it as **near-converged / mesh-stabilized**, not strictly converged
- the generic 7075 project static screen is exceeded
- the R8 geometry therefore requires redesign or a later allowable-based justification before any final design freeze

## Current design-response checkpoint — B14B-11F

Two reinforced-root concepts were generated from the R8 response target.

### F2_BALANCED

- root section: **95 × 115 mm**
- nominal blend: **R12 mm**
- added mass vs R8 head: approximately **0.615 kg**

1.0 mm local-screen result:

- mesh: **24,801 nodes / 14,487 elements**
- maximum deformation: **0.73252 mm**
- fillet-average VM: **77.072 MPa**
- fillet peak VM: **1995.7 MPa**
- peak location: approximately **(40.753, 37.334, 994.066) mm**

The average stress decreased by about **16.1%** from the retained R8 result while the local peak rose dramatically. The peak sits at/near the termination of the redesigned blend, identifying a local transition problem rather than a global section-load increase.

### Current disposition

**F2 V1 is rejected as-is.**

The **95 × 115 mm reinforced-root concept is retained** because the section response is promising, but the abrupt constant-radius blend termination must be replaced.

## Immediate next engineering step

**Design F2B**:

1. retain the **95 × 115 mm** root concept
2. replace the abrupt constant-radius blend termination with a smoother/tangent transition
3. preserve the established local-submodel cut/mapping convention
4. rerun the candidate at **1.0 mm quadratic local sizing**
5. inspect peak location, peak/average behavior, displacement consistency, and geometry credibility
6. only proceed to **0.75 mm** refinement after the 1.0 mm screen is physically credible
7. after local acceptance, update the full six-body parent and run the parent confirmation solve

F3 remains a fallback concept; it has not superseded the retained F2 section concept at this checkpoint.

## File-use rule

When multiple files cover the same analysis, prefer the highest/current revision identified in `UPLOAD_MANIFEST.md` and the explicit closeout/final-assessment records. Do not restore superseded development versions merely because they exist in an older local archive.

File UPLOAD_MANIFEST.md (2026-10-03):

# Upload Manifest

This repository is the curated GitHub state of the landing-gear project. The local working archive remains larger and may contain machine-specific environments, temporary solver material, and superseded development artifacts that are intentionally not versioned.

## Authoritative / latest core revisions

### Phase 1

- `phase1_loads/phase1_loads.py`
- `phase1_loads/phase1_dynamics.py`

### Phase 2 architecture / release chain

- `phase2_structures/phase2_traceability_audit_v04.py`
- `phase2_structures/phase2_traceability_v1_freeze_update.py`
- `phase2_structures/phase2e1_lower_end_architecture_v04.py`
- `phase2_structures/phase2e2_oleo_cavity_packaging_v03.py`
- `phase2_structures/phase2e2_metering_upper_head_layout_v04.py`
- `phase2_structures/phase2e2_metering_law_comparison_v03.py`
- `phase2_structures/phase2e2b_upper_head_closure_audit_v03.py`
- `phase2_structures/phase2e2c_fluid_continuity_closure_finalize_v01.py`
- `phase2_structures/phase2e2_v1_release_audit.py`

### Phase 2E3 B1–B13 retained chain

- `phase2_structures/phase2e3a_upper_attachment_source_audit_v01.py`
- `phase2_structures/phase2e3a2_upper_attachment_fbd_transport_v01.py`
- `phase2_structures/phase2e3b1_trunnion_centerline_trade_v01.py`
- `phase2_structures/phase2e3b2_trunnion_coupled_sizing_v01.py`
- `phase2_structures/phase2e3b3_trunnion_shortlist_head_integration_v01.py`
- `phase2_structures/phase2e3b4_cross_trunnion_head_interface_v01.py`
- `phase2_structures/phase2e3b5_local_head_interface_screen_v01.py`
- `phase2_structures/phase2e3b5a_barrel_material_upper_neck_audit_v01.py`
- `phase2_structures/phase2e3b5b_upper_barrel_reinforcement_profile_v01.py`
- `phase2_structures/phase2e3b6_head_span_recoupling_v01.py`
- `phase2_structures/phase2e3b6a_working_candidate_local_refresh_v02.py`
- `phase2_structures/phase2e3b7_transition_kt_budget_trade_v02.py`
- `phase2_structures/phase2e3b7a_expanded_transition_robustness_trade_v01.py`
- `phase2_structures/phase2e3b7b_transition_fea_handoff_v01.py`
- `phase2_structures/phase2e3b8_transition_fea_load_package_v01.py`
- `phase2_structures/phase2e3b9_fea_convergence_closeout_v01.py`
- `phase2_structures/phase2e3b9a_large_deflection_closeout_v01.py`
- `phase2_structures/phase2e3b10_upper_head_trunnion_integration.py`
- `phase2_structures/phase2e3b10a_retention_architecture_closeout.py`
- `phase2_structures/phase2e3b11_upper_head_local_screens.py`
- `phase2_structures/phase2e3b12_generate_integrated_model.py`
- `phase2_structures/current_design/phase2e3b13b_bushing_interface_sizing.py`
- `phase2_structures/current_design/phase2e3b13b_v02r1_interference_fit_min_ligament_correction.py`
- `phase2_structures/current_design/phase2e3b13b_v03_axial_thrust_flange_sizing.py`
- `phase2_structures/current_design/phase2e3b13b_v04_central_relief_trade.py`
- `phase2_structures/current_design/phase2e3b13c_build_geometry_portable_v2.py`

### B13F current-parent validation

- `phase2_structures/phase2e3_b13f3c_current_parent_validation_v01_resend.py`

Current retained parent STEP:

- `phase2_structures/phase2e3_b13f_3c_d44_r1p5_t3p5_left_collar_partial_relief.step`

### B14 physical brace / horn-clevis chain

- `phase2_structures/phase2e3b14a_ansys_reaction_documentation_v01.py`
- `phase2_structures/phase2e3b14b_brace_physicalization_v01.py`
- `phase2_structures/phase2e3b14b4_horn_clevis_detail_trade_v01.py`
- `phase2_structures/phase2e3b14b5_horn_robustness_shortlist_v01.py`
- `phase2_structures/phase2e3b14b6_head_packaging_gate_v01.py`
- `phase2_structures/phase2e3b14b7_saddle_root_reinforcement_trade_v01.py`
- `phase2_structures/phase2e3b14b8_physical_clevis_geometry_v01.py`
- `phase2_structures/phase2e3b14b9_build_physical_horn_clevis_v01.py`
- `phase2_structures/phase2e3b14b10_physical_brace_fea_handoff_v02.py`
- `phase2_structures/phase2e3b14b10_contact_geometry_audit_v01.py`
- `phase2_structures/phase2e3b14b10_contact_smoothing_diagnostic_v01.py`
- `phase2_structures/phase2e3b14b10_post_smoothing_linear_baseline_compare_v01.py`
- `phase2_structures/phase2e3b14b10_large_deflection_sensitivity_v01.py`
- `phase2_structures/phase2e3b14b10_closeout_record_v01.py`

### B14B-11 root-transition / local-FEA chain

- `phase2_structures/phase2e3b14b11_root_transition_trade_v01.py`
- `phase2_structures/phase2e3b14b11b_build_r6_root_fillet_v01.py`
- `phase2_structures/phase2e3b14b11_r6_local_convergence_closeout_v01.py`
- `phase2_structures/phase2e3b14b11c_build_r4_r8_trade_variants_v01.py`
- `phase2_structures/phase2e3b14b11c_corrected_r4_r6_r8_trade_v01.py`
- `phase2_structures/phase2e3b14b11c_r8_ridge_edge_refinement_assessment_v01.py`
- `phase2_structures/phase2e3b14b11d_build_r8_root_submodel_v01.py`
- `phase2_structures/phase2e3b14b11e_build_r8_root_local_solid_v01.py`
- `phase2_structures/phase2e3b14b11e_r8_fillet_convergence_v03_final_assessment.py`
- `phase2_structures/phase2e3b14b11f_r8_design_response_targets_v01.py`
- `phase2_structures/phase2e3b14b11f_root_redesign_trade_v01.py`
- `phase2_structures/phase2e3b14b11f_build_root_redesign_candidates_v01.py`
- `phase2_structures/phase2e3b14b11f_f2_balanced_screen_diagnostic_v01.py`

## Critical current records / CAD artifacts

### Frozen aircraft / oleo basis

- `phase1_loads/phase1_load_envelope.csv`
- `phase1_loads/phase1_dynamic_robustness.csv`
- `phase2_structures/phase2e2_v1_release_report.txt`
- `phase2_structures/phase2_traceability_register_v1.csv`
- `phase2_structures/phase2_open_validation_items_v1.csv`
- `phase2_structures/phase2_traceability_v1_summary.txt`

### Current-parent and B14 load-path records

- `phase2_structures/phase2e3_b13f3c_current_parent_record.csv`
- `phase2_structures/phase2e3_b13f3c_current_parent_summary.txt`
- `phase2_structures/phase2e3_b13f_3c_d44_r1p5_t3p5_left_collar_partial_relief.step`
- `phase2_structures/phase2e3b14a_freeze_record.csv`
- `phase2_structures/phase2e3b14a_summary.txt`
- `phase2_structures/phase2e3b14b9_head_horn_clevis_v01.step`
- `phase2_structures/phase2e3b14b9_summary.txt`
- `phase2_structures/phase2e3b14b10_closeout_summary_v01.txt`

### Current local-root / redesign records

- `phase2_structures/phase2e3b14b11_r6_local_convergence_closeout_v01.txt`
- `phase2_structures/phase2e3b14b11c_corrected_r4_r6_r8_trade_v01.txt`
- `phase2_structures/phase2e3b14b11d_r8_root_submodel_v01.step`
- `phase2_structures/phase2e3b14b11e_r8_root_local_solid_v01.step`
- `phase2_structures/phase2e3b14b11e_r8_fillet_convergence_v03_final_assessment.txt`
- `phase2_structures/phase2e3b14b11f_candidate_summary_v01.txt`
- `phase2_structures/phase2e3b14b11f_f2_balanced_full_sixbody_v01.step`
- `phase2_structures/phase2e3b14b11f_f2_balanced_local_submodel_v01.step`
- `phase2_structures/phase2e3b14b11f_f2_balanced_screen_diagnostic_v01.txt`
- `phase2_structures/phase2e3b14b11f_root_redesign_trade_v01.txt`

## Retained supporting analyses

The repository intentionally keeps unique trade, audit, sizing, FEA-handoff, convergence, and CAD-variant records when they provide engineering traceability, even when they are not the final/current design.

This includes:

- `phase1_model_development/` as a clearly labeled historical Phase 1 archive
- B1–B12 design trade history
- B13/B13F geometry-development variants and reports
- B14 brace, horn/clevis, packaging, and CAD handoff records
- B14B-10 contact/setup diagnostics
- B14B-11 R4/R6/R8 radius-trade and convergence diagnostics
- R8 local-submodel construction and validation records
- F2/F3 redesign-candidate CAD and screening records
- documentation backfill / traceability audit outputs that improve the engineering record

## Current checkpoint

The current design checkpoint is **B14B-11F after the F2_BALANCED 1.0 mm local screen**.

- retained R8 local peak: **732.45 MPa @ 0.75 mm**
- F2 root section: **95 × 115 mm**, nominal **R12** blend
- F2 fillet-average VM: **77.072 MPa**
- F2 local peak: **1995.7 MPa** at the new blend termination
- disposition: **F2 V1 rejected as-is; reinforced-section concept retained**

Next engineering action: **F2B transition redesign** with a smoother/tangent blend termination, followed by a repeat 1.0 mm quadratic local screen.

## Intentionally excluded from GitHub

### Machine / IDE material

- `phase2_structures/.venv_cad/` — local Windows Python/CadQuery environment; recreate from `requirements.txt`
- any other `.venv*`, `venv/`, cache, or compiled-bytecode directories
- `*.code-workspace` — local editor workspace state

### Known superseded / unwanted artifacts

The earlier exclusions remain in force, including superseded Phase 2 traceability/E1/E2 revisions, superseded B6A/B7 revisions, obsolete B13B V0.2 interference-fit outputs, and the older B13C builders superseded by `portable_v2`.

Additionally:

- `phase2_structures/phase2e3b7a_working_profile.csv` — empty artifact from a trade with no passing working profile; do not restore it

## Recommended reading order for continuation

1. `CURRENT_STATE.md`
2. `phase1_loads/phase1_load_envelope.csv`
3. `phase1_loads/phase1_dynamic_robustness.csv`
4. `phase2_structures/phase2e2_v1_release_report.txt`
5. `phase2_structures/phase2e3_b13f3c_current_parent_summary.txt`
6. `phase2_structures/phase2e3b14a_summary.txt`
7. `phase2_structures/phase2e3b14b9_summary.txt`
8. `phase2_structures/phase2e3b14b10_closeout_summary_v01.txt`
9. `phase2_structures/phase2e3b14b11_r6_local_convergence_closeout_v01.txt`
10. `phase2_structures/phase2e3b14b11e_r8_fillet_convergence_v03_final_assessment.txt`
11. `phase2_structures/phase2e3b14b11f_root_redesign_trade_v01.txt`
12. `phase2_structures/phase2e3b14b11f_f2_balanced_screen_diagnostic_v01.txt`

At this snapshot, F2B has **not** yet been generated; it is the next design task.

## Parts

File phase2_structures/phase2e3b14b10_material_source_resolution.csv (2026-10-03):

quantity | current_value | units | current_source | historical_value | historical_source | disposition | note
brace_tube_OD | 25.0 | mm | phase2e3b14b_brace_physicalization_v01.py |  |  | CURRENT_B14B | Current B14B working tube outer diameter.
brace_tube_wall | 3.0 | mm | phase2e3b14b_brace_physicalization_v01.py |  |  | CURRENT_B14B | Current B14B working tube wall thickness.
E_300M | 200000.0 | MPa | phase2e3b14b_brace_physicalization_v01.py | 205000.0 | phase2_upper_brace_sizing.py | USE_LATER_B14B_VALUE | Later B14B physicalization controls this branch. Earlier Phase 2D10 modulus is retained only for traceability.

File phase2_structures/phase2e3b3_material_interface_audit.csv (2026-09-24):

audit_item | finding | status | design_consequence
Trunnion journal material | D9 explicitly models each journal as a solid 300M-steel cantilever root. | SOURCE_CONFIRMED | B2 journal stress results are valid only for the D9 300M journal concept and its preliminary allowable convention.
Barrel / upper-head material baseline | 7075-T6 PROJECT FROZEN BASELINE (traceability text token not automatically found) | PROJECT_BASELINE | A 300M journal cannot be silently treated as integral with a 7075-T6 barrel/head. A real material/interface architecture must be defined.
Steel-to-head load-transfer interface | No frozen E2/D9 definition of how the 300M trunnion journal is structurally fixed to the upper head was identified by this audit. | OPEN_BLOCKING_FINAL_FREEZE | Do not freeze final trunnion diameter/station until the journal-to-head load path is selected and screened.
Working architecture A | 300M through-trunnion / cross-shaft rigidly captured by a locally enlarged 7075-T6 solid head boss. | CANDIDATE | Preserves E2 aluminum barrel/head baseline and D9 300M journal allowables, but requires shaft-to-head bearing/contact, retention, fretting/fatigue and local 7075 boss checks.
Working architecture B | Separate 300M trunnion/head module joined structurally to the 7075-T6 barrel above the pressure closure. | CANDIDATE | Allows integral steel journals but introduces a major steel-to-aluminum barrel/head joint carrying the upper structural loads.
Working architecture C | Integral 7075-T6 trunnion journals formed with the upper head. | CANDIDATE_REQUIRES_RESIZING | Invalidates the current 300M journal sizing and would require a new journal/wear-surface sizing study.

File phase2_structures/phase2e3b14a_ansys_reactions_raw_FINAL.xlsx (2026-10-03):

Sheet: B14A Raw Inputs
case | load_case_id | model_name | analysis_name | result_name | support_name | pressure_MPa | applied_Fx_N | applied_Fy_N | applied_Fz_N | applied_Mx_Nmm | applied_My_Nmm | applied_Mz_Nmm | brace_Rx_N | brace_Ry_N | brace_Rz_N | brace_Mx_Nmm | brace_My_Nmm | brace_Mz_Nmm | left_Rx_N | left_Ry_N | left_Rz_N | right_Rx_N | right_Ry_N | right_Rz_N | source_note
combined | LC4+_ULT | B14A_LC4PLUS_BRACE_REACTION_AUDIT | Static Structural | Moment Reaction | SUP_BRACE_RX | 13.938 |  |  |  | 12942846 | 0 | 0 |  |  |  | -16856000 | 0 | 0 |  |  |  |  |  |  | Known from prior B14A ANSYS work/current screenshot. Remote Force = (0,+12510,+16638) N and pressure = 13.938 MPa, but combined applied_F fields are intentionally blank because the equivalent pressure force resultant has not been extracted.
force_only | LC4+_ULT | B14A_LC4PLUS_BRACE_REACTION_AUDIT | Static Structural | Moment Reaction | SUP_BRACE_RX | 0 | 0 | 12510 | 16638 | 0 | 0 | 0 |  |  |  | -3912800 |  |  |  |  |  |  |  |  | Recovered from prior B14A ANSYS work: force-only SUP_BRACE_RX Mx = -3.9128e6 N*mm. Remote Force = (0,+12510,+16638) N.
moment_only | LC4+_ULT | B14A_LC4PLUS_BRACE_REACTION_AUDIT | Static Structural | Moment Reaction | SUP_BRACE_RX | 0 | 0 | 0 | 0 | 12942846 | 0 | 0 |  |  |  | -12943000 |  |  |  |  |  |  |  |  | Raw ANSYS screenshot: SUP_BRACE_RX Moment Reaction X at final Time = 1.0 s = -1.2943e+007 N·mm. Remote Moment input = +12,942,846 N·mm about X.
pressure_only | LC4+_ULT | B14A_LC4PLUS_BRACE_REACTION_AUDIT | Static Structural | Moment Reaction | SUP_BRACE_RX | 13.938 |  |  |  |  |  |  |  |  |  | 12.312 |  |  |  |  |  |  |  |  | Raw ANSYS screenshot: SUP_BRACE_RX Moment Reaction X at final Time = 1.0 s = +12.312 N·mm for the pressure-only case.

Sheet: Read Me
B14A ANSYS Raw Reaction Input — Prefilled
Purpose | Final B14A raw-reaction input populated from prior B14A work and the current ANSYS screenshots.
Combined | brace_Mx_Nmm = -16,856,000 N·mm
Force only | brace_Mx_Nmm = -3,912,800 N·mm
Moment only | brace_Mx_Nmm = -12,943,000 N·mm
Pressure only | brace_Mx_Nmm = +12.312 N·mm
Next step | Run phase2e3b14a_ansys_reaction_documentation_v01.py using the final CSV.

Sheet: B14A Check
B14A Brace-Reaction Decomposition Check
Quantity | Value
Combined Mx [N·mm] | -16856000.000
Force-only Mx [N·mm] | -3912800.000
Moment-only Mx [N·mm] | -12943000.000
Pressure-only Mx [N·mm] | 12.312
Reconstructed Mx [N·mm] | -16855787.688
Residual [N·mm] | -212.312
Residual [% of |combined|] | 0.001260

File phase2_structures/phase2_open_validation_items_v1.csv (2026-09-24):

item_id | phase | category | parameter | value | units | classification | status | source_or_derivation | engineering_basis | limitation_or_validation | sensitivity_or_consequence
P0-004 | Phase 0 | Certification | Certification-level substantiation | not yet claimed | - | NEEDS_VALIDATION | OPEN_VALIDATION | Project scope boundary | Current work is a preliminary engineering design study. | Applicable FAA/EASA landing-load requirements should be explicitly mapped before claiming certification compliance. | High — affects formal load cases and margins.
P1-006 | Phase 1 | Landing dynamics | Seal friction / stiction | neglected | - | MODEL_ASSUMPTION | OPEN_VALIDATION | C:\Users\Shahi\OneDrive\Documents\Python\Landing_Gear_Project\phase1_model_development\landing_dynamic_v04_2dof.py | Simplified oleo dynamic model. | Real seals add breakaway force and hysteresis. | Moderate for low-speed response; possibly significant near reversals.
P1-007 | Phase 1 | Landing dynamics | Oil compressibility | neglected | - | MODEL_ASSUMPTION | OPEN_VALIDATION | C:\Users\Shahi\OneDrive\Documents\Python\Landing_Gear_Project\phase1_model_development\landing_dynamic_v04_2dof.py | Incompressible-fluid approximation. | Bulk modulus / entrained gas not represented. | Usually secondary for preliminary sizing; relevant to pressure transients.
P1-008 | Phase 1 | Landing dynamics | Temperature-dependent viscosity | neglected | - | MODEL_ASSUMPTION | OPEN_VALIDATION | C:\Users\Shahi\OneDrive\Documents\Python\Landing_Gear_Project\phase1_model_development\landing_dynamic_v04_2dof.py | Constant effective oil property. | Cold / hot oil can significantly change damping. | High for operational envelope robustness.
P1-009 | Phase 1 | Landing dynamics | Cavitation / aeration / foaming | not explicitly modeled | - | MODEL_ASSUMPTION | OPEN_VALIDATION | C:\Users\Shahi\OneDrive\Documents\Python\Landing_Gear_Project\phase1_model_development\landing_dynamic_v04_2dof.py | Single-phase hydraulic treatment. | Direct N2-over-oil architecture requires later interface / aeration assessment. | Potentially high for repeated-cycle behavior.
P2-005 | Phase 2E1 | Local stress | Lower-end stress-concentration factor | Kt = 1.5 baseline; sensitivity checked to 3.0 | - | MODEL_ASSUMPTION | OPEN_VALIDATION | C:\Users\Shahi\OneDrive\Documents\Python\Landing_Gear_Project\phase2_structures\phase2e1_lower_end_geometry.csv | Provides conservative screening before final local geometry exists. | Must be replaced / supported by final CAD stress concentration or 3D FEA. | High at piston/knuckle transitions.
P2E2-016 | Phase 2E2 | Oleo architecture | Metering-pin support stiffness / buckling | not yet analyzed in detail | - | NEEDS_VALIDATION | OPEN_VALIDATION | Phase 2E2 limitation register | Current model treats the profiled pin as geometrically ideal. | Analyze lateral support, buckling, vibration and eccentricity. | Could affect metering repeatability.
P2E2-017 | Phase 2E2 | Oleo architecture | Pressure closure local details | not yet modeled | - | NEEDS_VALIDATION | OPEN_VALIDATION | Phase 2E2 release boundary | 6 mm result is a global plate screen only. | Seal groove, retainer/thread, ports and local FEA required. | Potential local stress driver.
V-001 | Project-wide | Final validation | Fatigue / spectrum loading | not yet completed | - | NEEDS_VALIDATION | OPEN_VALIDATION | End-of-project validation plan | Necessary to move from preliminary design toward detailed/certification-level substantiation. | Repeated landing / taxi cycles require fatigue evaluation. | High
V-002 | Project-wide | Final validation | 3D local FEA | not yet completed | - | NEEDS_VALIDATION | OPEN_VALIDATION | End-of-project validation plan | Necessary to move from preliminary design toward detailed/certification-level substantiation. | Required for knuckle, axle transitions, barrel/head and trunnion detail. | High
V-003 | Project-wide | Final validation | Manufacturing tolerances / fits | not yet completed | - | NEEDS_VALIDATION | OPEN_VALIDATION | End-of-project validation plan | Necessary to move from preliminary design toward detailed/certification-level substantiation. | Needed for piston/barrel running fit, bushings, pin and bearing interfaces. | High
V-004 | Project-wide | Final validation | Corrosion / surface treatment | not yet completed | - | NEEDS_VALIDATION | OPEN_VALIDATION | End-of-project validation plan | Necessary to move from preliminary design toward detailed/certification-level substantiation. | Material allowables and wear surfaces require environmental/detail definition. | High
V-005 | Project-wide | Final validation | Certification load-case mapping | not yet completed | - | NEEDS_VALIDATION | OPEN_VALIDATION | End-of-project validation plan | Necessary to move from preliminary design toward detailed/certification-level substantiation. | Map project load cases to applicable regulatory landing conditions. | High

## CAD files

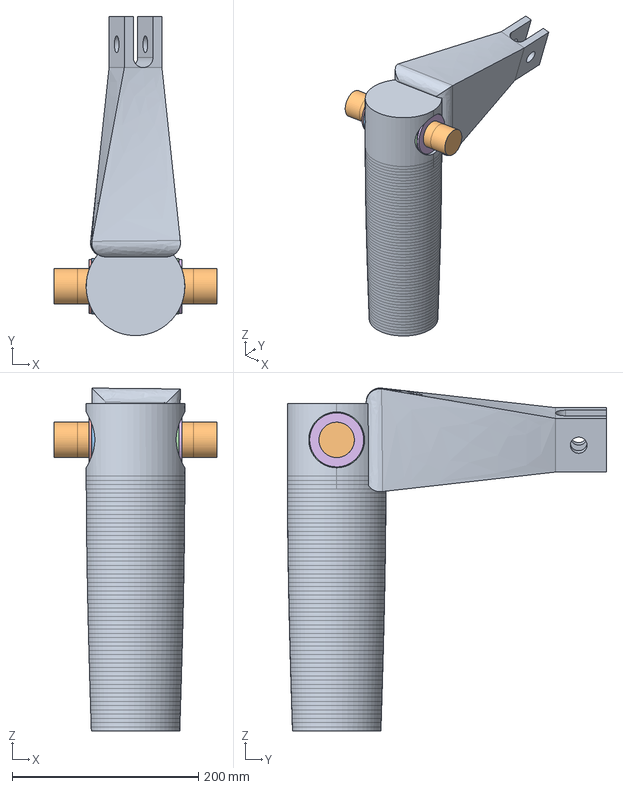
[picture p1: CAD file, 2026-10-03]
phase2_structures/phase2e3b14b11f_f3_robust_full_sixbody_v01.step
175.0 x 343.0 x 368.5 mm
HEAD_BARREL_7075
SHAFT_300M_CONTINUOUS
BUSHING_LEFT_AMS4640
BUSHING_RIGHT_AMS4640
THRUST_COLLAR_LEFT_300M
THRUST_COLLAR_RIGHT_300M

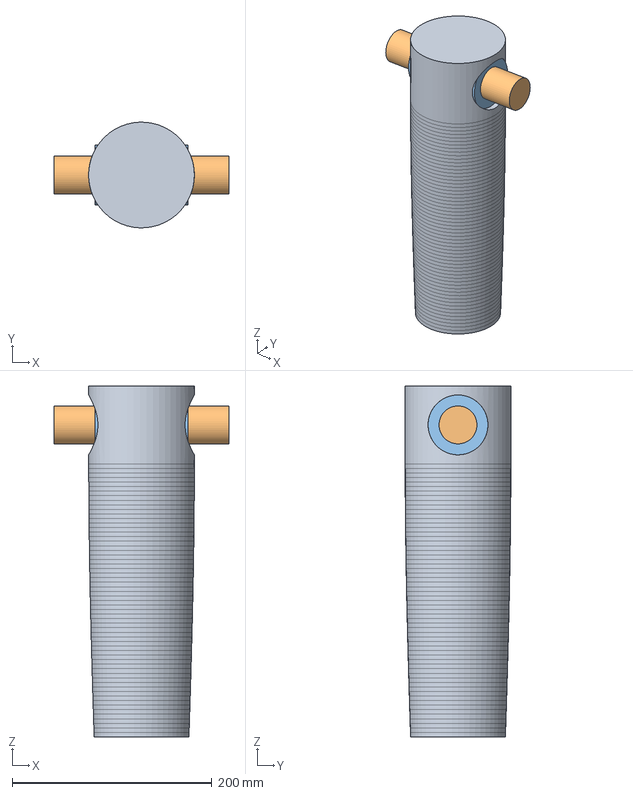
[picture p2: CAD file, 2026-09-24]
phase2_structures/current_design/phase2e3b13c_bushed_head_trunnion.step
175.0 x 105.9 x 351.8 mm
HEAD_BARREL_7075
SHAFT_300M_CONTINUOUS
BUSHING_LEFT_AMS4640
BUSHING_RIGHT_AMS4640

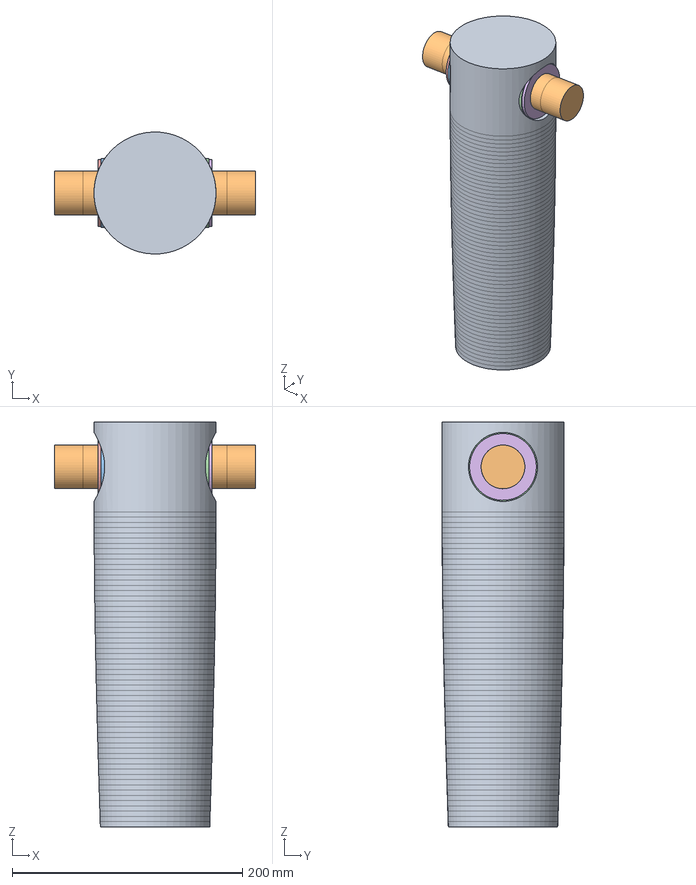
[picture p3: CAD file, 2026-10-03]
phase2_structures/phase2e3_b13f_3a_d44_r1p5_left_collar_annular_seat.step
175.0 x 105.9 x 351.8 mm
HEAD_BARREL_7075
SHAFT_300M_CONTINUOUS
BUSHING_LEFT_AMS4640
BUSHING_RIGHT_AMS4640
THRUST_COLLAR_LEFT_300M
THRUST_COLLAR_RIGHT_300M

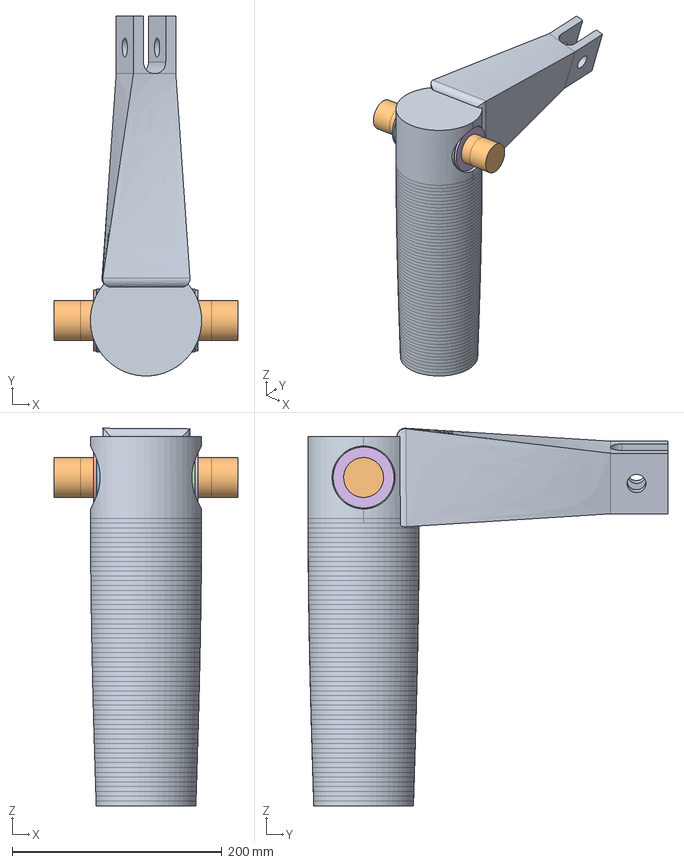
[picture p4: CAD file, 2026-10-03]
phase2_structures/phase2e3b14b11c_r8_root_fillet_candidate_v01.step
175.0 x 343.0 x 359.8 mm
HEAD_BARREL_7075
SHAFT_300M_CONTINUOUS
BUSHING_LEFT_AMS4640
BUSHING_RIGHT_AMS4640
THRUST_COLLAR_LEFT_300M
THRUST_COLLAR_RIGHT_300M

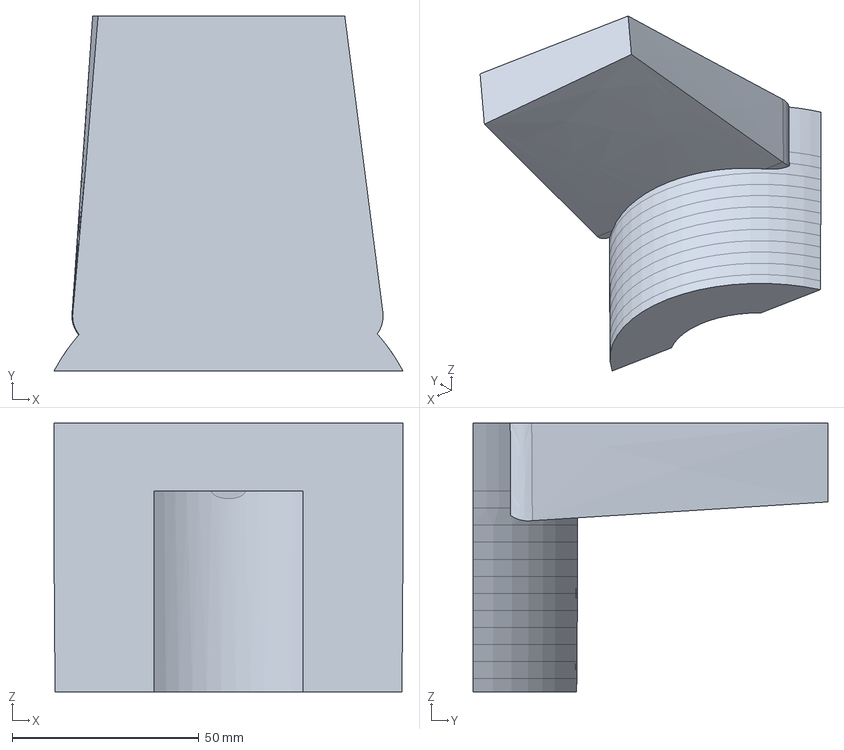
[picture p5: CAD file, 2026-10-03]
phase2_structures/phase2e3b14b11e_r8_root_local_solid_v01.step
93.5 x 95.0 x 72.0 mm

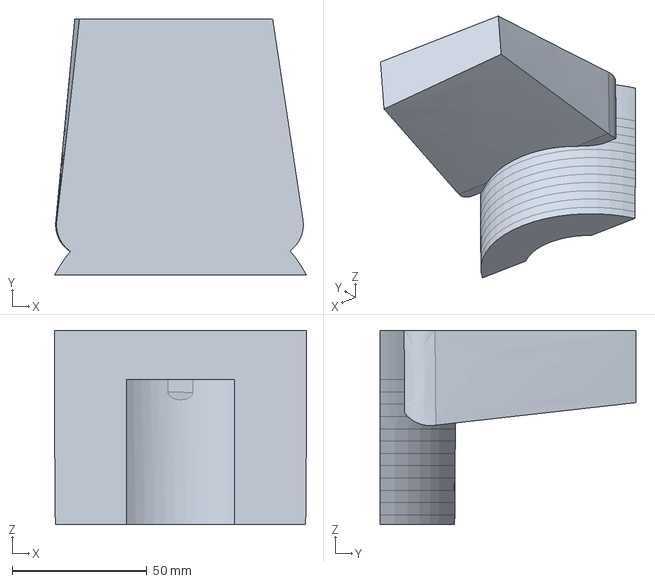
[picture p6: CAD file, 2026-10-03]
phase2_structures/phase2e3b14b11f_f2_balanced_local_submodel_v01.step
93.5 x 95.0 x 72.0 mm

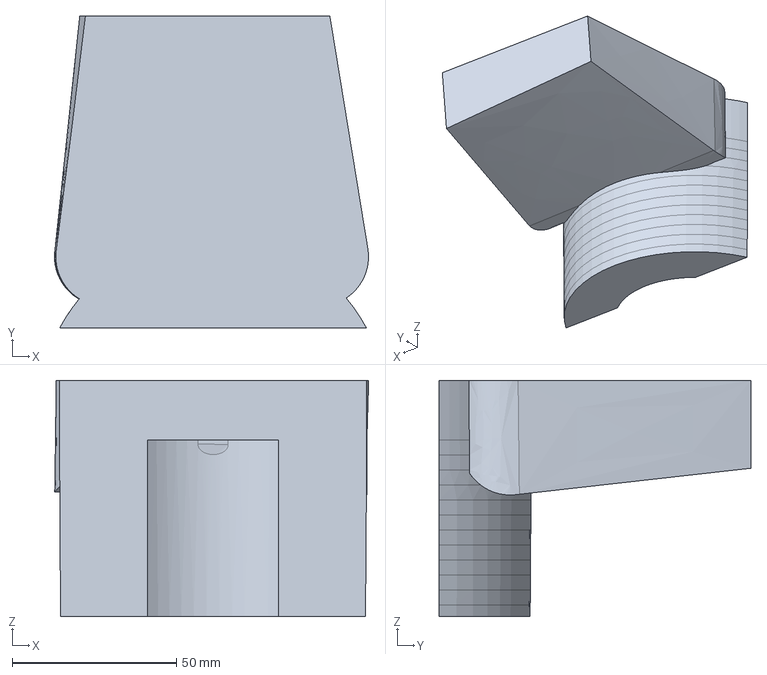
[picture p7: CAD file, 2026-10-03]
phase2_structures/phase2e3b14b11f_f3_robust_local_submodel_v01.step
95.7 x 95.0 x 72.0 mm

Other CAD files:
phase2_structures/phase2e3b14b11f_f2_balanced_full_sixbody_v01.step
phase2_structures/phase2e3b13c_bushed_head_trunnion_support_faces.step
phase2_structures/phase2e3_b13f_2c_d44_left_bushing_r2p0.step
phase2_structures/phase2e3_b13f_3c_d44_r1p5_t3p5_left_collar_partial_relief.step
phase2_structures/phase2e3_b13f_3b_d44_r1p5_left_flange_t3p5.step
phase2_structures/phase2e3_b13f_1a_d46_bushed_head_trunnion.step
phase2_structures/phase2e3_b13f_1c_d42_bushed_head_trunnion.step
phase2_structures/phase2e3_b13f_2b_d44_left_bushing_r1p5.step
phase2_structures/phase2e3b14b9_head_horn_clevis_v01.step
phase2_structures/phase2e3b13g1_bushed_head_trunnion_with_thrust_collars.step
phase2_structures/phase2e3_b13f_1b_d44_bushed_head_trunnion.step
phase2_structures/phase2e3_b13f_2a_d44_left_bushing_r1p0.step
phase2_structures/phase2e3b12_integrated_head_trunnion.step
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

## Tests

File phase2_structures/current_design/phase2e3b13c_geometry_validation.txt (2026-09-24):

============================================================================================================
 PHASE 2E3-B13C — GENERATED BUSHED UPPER-HEAD GEOMETRY VALIDATION
============================================================================================================
Source STEP:                         phase2e3b12_integrated_head_trunnion(1).step
Output STEP:                         phase2e3b13c_bushed_head_trunnion.step
Imported B12 solid count:            4
Exported/re-imported solid count:    4

--- WORKING GEOMETRY ---
Upper-head outer boss:               Ø106.000 mm x 78.000 mm high
Head passage:                        Ø50.000 mm THROUGH
Continuous 300M shaft:               Ø38.000 mm x 175.000 mm
Bronze sleeve, each side:            Ø50.000/Ø38.000 x 30.000 mm
Bronze flange, each side:            Ø60.000/Ø38.000 x 3.000 mm

--- CURVED-HEAD FLANGE SEAT CORRECTION ---
The source head exterior at the trunnion is a Ø106 cylinder about global Z,
not a planar ±X face. A real flange therefore needs planar spotfaces.
Full-Ø60 tangent-safe spotface plane: X = ±43.692105 mm
Spotface depth at Y=0 from Ø106 tangent: 9.307895 mm
Bushing sleeve inner ends:            X = ±13.692105 mm
Unoccupied central Ø50 passage:       27.384209 mm
Shaft-to-7075 radial clearance there: 6.000 mm

--- BODY BOUNDING BOXES / VOLUMES ---
HEAD_BARREL_7075              V= 1837596.560 mm^3  X[  -53.000,   53.000] Y[  -53.000,   53.000] Z[  700.000, 1051.780]
SHAFT_300M_CONTINUOUS         V=  198470.116 mm^3  X[  -87.500,   87.500] Y[  -19.000,   19.000] Z[  993.780, 1031.780]
BUSHING_LEFT_AMS4640          V=   29961.369 mm^3  X[  -46.692,  -13.692] Y[  -30.000,   30.000] Z[  982.780, 1042.780]
BUSHING_RIGHT_AMS4640         V=   29961.369 mm^3  X[   13.692,   46.692] Y[  -30.000,   30.000] Z[  982.780, 1042.780]

--- INTERSECTION VOLUME CHECK ---
head-shaft                  : 0.000000000 mm^3
head-left_bushing           : 0.000000000 mm^3
head-right_bushing          : 0.000000000 mm^3
shaft-left_bushing          : 0.000000000 mm^3
shaft-right_bushing         : 0.000000000 mm^3
left-right_bushing          : 0.000000000 mm^3

INTERPRETATION
- Four separate physical bodies are delivered: 7075 head, one 300M shaft, two bronze bushings.
- Ø50 through-cut supersedes the B12C Ø38 bore and its 1.5 mm diagnostic mouth chamfers.
- Shaft/head direct contact is geometrically impossible in the central relief region (6 mm radial gap).
- Bronze/head OD and bronze/shaft ID are nominally coincident surfaces for contact definition in ANSYS.
- The Ø60 flanges now seat on explicit planar Ø60 spotfaces cut into the curved Ø106 head exterior.
- Spotface root/edge detail is intentionally sharp and remains a local FEA/detail-design sensitivity.
============================================================================================================

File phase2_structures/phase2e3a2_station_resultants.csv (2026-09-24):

station_label | extra_above_E2_boundary_mm | station_above_U_mm | station_above_A_static_mm | level | case | Fx_kN | Fy_kN | Fz_kN | Mx_kNm | My_kNm | Mz_kNm | resultant_moment_kNm | transport_residual_Mx_kNm | transport_residual_My_kNm | transport_residual_Mz_kNm
E2_BOUNDARY | 0.0 | 498.780356685791 | 973.780356685791 | limit | LC0 | 0.0 | 0.0 | 7.452765957446808 | 0.894331914893617 | -0.0 | -0.0 | 0.894331914893617 | 0.0 | 0.0 | 0.0
E2_BOUNDARY | 0.0 | 498.780356685791 | 973.780356685791 | limit | LC1 | 0.0 | 0.0 | 25.02 | 3.0023999999999997 | -0.0 | -0.0 | 3.0023999999999997 | 0.0 | 0.0 | 0.0
E2_BOUNDARY | 0.0 | 498.780356685791 | 973.780356685791 | limit | LC2A | -6.255 | 0.0 | 25.02 | 3.0023999999999997 | 7.185621131069623 | 0.7505999999999999 | 7.823743168028606 | 0.0 | 8.881784197001252e-16 | 0.0
E2_BOUNDARY | 0.0 | 498.780356685791 | 973.780356685791 | limit | LC2B | 6.255 | 0.0 | 25.02 | 3.0023999999999997 | -7.185621131069623 | -0.7505999999999999 | 7.823743168028606 | 0.0 | -8.881784197001252e-16 | 0.0
E2_BOUNDARY | 0.0 | 498.780356685791 | 973.780356685791 | limit | LC3 | 0.0 | 0.0 | 25.02 | 3.0023999999999997 | -0.0 | -0.0 | 3.0023999999999997 | 0.0 | 0.0 | 0.0
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

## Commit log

2026-09-24 Add complete aircraft landing gear design project
    Add Phase 1 load and landing-dynamics models, Phase 2 structural sizing analyses, CAD/STEP geometry, engineering outputs, and project documentation.
    [FILE_INVENTORY.csv, phase1_dynamic_robustness.csv, phase1_load_envelope.csv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]
2026-09-24 Update README remaining work
    Add CATIA V5 detailed landing-gear assembly development to the planned project scope.
2026-10-03 Advance upper gear structural design through B14B-11F root FEA
    - Add Phase 2 upper-gear structural design updates
    - Add B13F-3C retained parent configuration
    - Add B14/B14B horn-clevis and physical-brace development
    - Add B14B-10 FEA closeout and R6/R8 local refinement studies
    - Add R8 mesh-convergence results, retaining 732.45 MPa at 0.75 mm
    - Add F2 reinforced-root redesign results and F2B work-in-progress state
    - Update README, CURRENT_STATE, UPLOAD_MANIFEST, FILE_INVENTORY, and .gitignore
    [FILE_INVENTORY.csv, phase2_documentation_summary_backfill_v01.csv, phase2_documentation_summary_backfill_v02.csv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]
